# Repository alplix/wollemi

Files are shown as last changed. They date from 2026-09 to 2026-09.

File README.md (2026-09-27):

# Wollemi

> **Private for now.** The repository will be opened to the public once the design is complete. No licence has been applied yet; the plan (`docs/licensing.md`) is CERN-OHL-S-2.0 for hardware,
> Apache-2.0 for software and CC-BY-4.0 for documents. Analysis-level design only: no hardware exists, nothing here is qualified for flight, and every number is an engineering estimate.

Wollemi is an open, modular, fully documented small-satellite **platform** and a first mission built on it: a science-first, long-life **12U observatory** with a tiered 50-year survival design.
Everything is generated from configuration files and checked by tools, so a derived mission is a configuration change plus new cards.

*Türkçe özet:* Wollemi, açık kaynak, modüler bir küçük uydu platformu ve üzerine kurulu ilk görev: uzun ömürlü, bilim öncelikli 12U gözlemevi. Tasarım analiz düzeyinde tamamlandı (donanım yok);
her sayı config dosyalarından üretilen araçlarla doğrulanıyor. Depo şimdilik özel, tasarım olgunlaşınca herkese açılacak.

## Where things stand

The design is **complete at analysis level**: requirements, architecture, CAD with interference checks, power/thermal/attitude/orbit/structure analyses, protocol and firmware core with tests,
electronics interface (KiCad, DRC clean), FMEA, test plan, operations concept, cost and schedule. Start with **`docs/sdd.md`** (system design document) and **`docs/status.md`** (latest regression).
What is missing is physical: vendor data, schematics of the functional cards, prototypes, tests, a launch and an operator. See `docs/plan.md`, `docs/risks.md` and `docs/cost.md`.

| At a glance | Value |
|---|---|
| Form | 12U CubeSat envelope, 2 x 2 x 3 cell grid around a central spine, notched 100 x 100 mm cards |
| Mass / power | about 16.8 kg of 24 kg; 58 W sun-biased, 28 W tumbling, 3 W safe-mode load |
| Science | ~26 instruments: telescope (5 m class) + hyperspectral, thermal IR, magnetometer, particles, X-ray/UV, TSI, VLF, GRB, dosimetry, SEU/flash experiments |
| Compute | MSP430 supervisor, 2 x STM32H7, mass memory unit (8 x 128 GB, 6+2), Pi CM5, Jetson Orin Nano |
| Power | two LiFePO4 chains + independent survival chain, hardware-only protection |
| Propulsion | iodine electric thruster on the centre line, ~570 m/s available (about 190 m/s planned), drag sail |
| Verification | 47 requirements traced (see `docs/verification-matrix.md`); most checked automatically on every run; 29 planned tests |

## Documentation

| Topic | Read |
|---|---|
| Overview | `docs/sdd.md`, `docs/plan.md`, `docs/status.md` |
| Requirements and verification | `mission/requirements.md`, `docs/verification-matrix.md`, `docs/test-plan.md`, `docs/fmea.md`, `docs/risks.md` |
| Design | `docs/architecture.md`, `docs/layout.md`, `docs/structure.md`, `docs/icd.md`, `mechanical/README.md` |
| Power, thermal, attitude, propulsion | `docs/power-architecture.md`, `docs/eps-card.md`, `docs/thermal.md`, `docs/adcs.md`, `docs/propulsion.md`, `docs/orbit-and-debris.md` |
| Electronics, software, data | `docs/electrical-interface.md`, `docs/firmware-architecture.md`, `docs/protocol.md`, `docs/data-plan.md`, `docs/mission-simulation.md` |
| Operations and ground | `docs/ops-concept.md`, `docs/ground-station-kit.md`, `docs/longevity.md` |
| Context | `docs/sponsor-brief.md`, `docs/relay-policy.md`, `docs/prior-art.md`, `docs/design-identity.md`, `docs/decisions/`, `docs/outreach-led.md`, `docs/cost.md`, `docs/licensing.md`, `CREDITS.md` |

## Repository layout

| Path | Content |
|---|---|
| `configs/` | Single source of truth: science, geometry, layout, data, longevity, thermal, structure, cost (+ 2U/3U/6U variants) |
| `mission/` | Requirements, `traceability.toml` (requirement -> verification), `tests.toml` (planned tests), `fmea.toml` |
| `sim/` | Budgets, layout rules, balance, data, longevity, link, EPS, ADCS, thermal, structure, orbit lifetime, mission simulation, cost, LED visibility, live verification matrix |
| `mechanical/` | Voxel packing, parametric build123d assembly, interference/mass properties, STEP/STL/renders |
| `electronics/` | Connector pinout (single source), KiCad card template and 15-slot backplane strip (DRC clean), EPS diagram, EPS/survival card floor plans (DRC clean, not yet a schematic) |
| `protocol/` | Message definitions, C/Python/Kaitai Struct generators, tests (round trip, corruption, byte-exact C <-> Python, Kaitai model verified against a real compiler) |
| `firmware/` | Host-testable core: Ed25519 command authentication, modes, FDIR, command queue, A/B OTA (84 unit checks + signature cross-checks) |
| `groundstation/` | Pass prediction, contact plan, reference decoder, Kaitai Struct decoders for the whole protocol |
| `tools/` | `check_all.py` (whole regression), FMEA, test-plan and requirement checks, generators for the ICD and the SDD |
| `site/` | Draft project website (English), prepared but not published -- repository is still private (`site/README.md`) |

## Quick start

```
pip install build123d cryptography sgp4       # CAD kernel, signing tests, orbit propagation (numpy, scipy, pillow come with build123d); KiCad 10 optional for DRC
python tools/check_all.py                     # runs every analysis and test, writes docs/status.md   (--quick skips CAD, thermal and the verification matrix)
python sim/trace_check.py                     # live requirements verification matrix
python mechanical/wollemi_cad.py               # full CAD assembly and checks, exports into mechanical/out/
python tools/gen_sdd.py                       # regenerate the system design document
```

Requires Python 3.11+ and GCC for the firmware and protocol tests. The `sim/` tools use only the standard library unless noted.

## Status and next steps

Design freeze candidate v0 at analysis level. The decisions that shape everything next: choose the target (flight mission, flight-quality reference design, or the precursor path with a FlatSat and a balloon flight),
confirm the preferred orbit, and get vendor quotes and datasheets. Details in `docs/sdd.md` section 8.

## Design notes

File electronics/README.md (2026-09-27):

# Electronics

| File | Role |
|---|---|
| `card_pinout.toml` | Single source for the WL-P and WL-D connector pinouts and the card outline |
| `gen_card.py` | Generates the KiCad card template and `pinout.md`, runs `kicad-cli` DRC (needs KiCad 10) |
| `kicad/wollemi_card_template.kicad_pcb` | 100 x 100 mm card with the 20 x 20 mm spine notch, 4 x M2.5 holes, edge-guide keep-outs, WL-P and WL-D connector placeholders with every net assigned |
| `kicad/wollemi_card_template.svg`, `_top.png` | Renders |
| `gen_backplane.py` | Generates the 15-slot passive backplane strip (one per column), runs `kicad-cli` DRC |
| `kicad/wollemi_backplane_strip.kicad_pcb` | Passive backplane strip: 15 card slots, WL-P/WL-D routing per chain, DRC clean |
| `gen_eps_card.py` | Generates function-block floor plans for the EPS-A/EPS-B and survival cards on the real card outline (`docs/eps-card.md`), runs `kicad-cli` DRC |
| `kicad/wollemi_eps_card.kicad_pcb`, `wollemi_survival_card.kicad_pcb` | Floor plans only: labelled placeholder blocks proving the partition fits the card, DRC clean; not a routed schematic |
| `eps_diagram.py` | Generates the EPS block diagram `eps_diagram.svg` |
| `pinout.md` | Generated pin tables |

```
python electronics/gen_card.py
python electronics/gen_backplane.py
python electronics/gen_eps_card.py
```

The card template has no routing yet: `unconnected_items` and generated-library warnings are silenced in its project file on purpose. Cards derived
from it must re-enable them. Connector footprints are placeholders (2-row, 1.27 mm pitch pads); replace with the vendor footprint once the
connector family is chosen (`docs/electrical-interface.md`).

Next: choose real parts and capture a routed schematic for the EPS and survival cards (`docs/eps-card.md`); a first functional (non-EPS) card schematic.

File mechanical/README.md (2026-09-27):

# Mechanical model (parametric CAD)

Everything is generated from the TOML configs; nothing is hand-drawn.

| File | Role |
|---|---|
| `../configs/12u_geometry.toml` | Frame, wings and a bounding box (mm) for every module; flags `fixed`, `shape = "cyl"`, `notched`, `end = "nadir"/"zenith"`, `align = "top"` |
| `pack.py` | Voxel packing (2.5 mm) of every box into its assigned column/deck; maximum-contact placement, disk footprints for cylinders, corner-notched card format; writes `out/placement.json` |
| `wollemi_cad.py` | build123d / OpenCascade assembly: rails, walls, plates with windows, bulkheads, spine, modules, wings, antennas, thruster nozzle; exact boolean interference check; centre of mass and inertia; STEP, STL, renders, BOM |

```
pip install build123d            # OpenCascade based CAD kernel (also pulls numpy, scipy, pillow)
python mechanical/pack.py        # packing report
python mechanical/wollemi_cad.py  # full assembly, checks, exports into mechanical/out/
```

Outputs in `out/`: `wollemi_12u_stowed.step/.stl`, `wollemi_12u_deployed.step/.stl`, `render_*.png`
(stowed, deployed, interior, cutaway, nadir), `bom_geometry.csv`, `placement.json`.

## What the geometry taught us

- **Volume was not the problem, footprint was.** The 20 x 20 mm spine notch at every column's inner corner
  stops any 90 x 90 mm or 100 x 100 mm board. Fix: the **Wollemi card format**, a board with its own
  20 x 20 mm corner cut-out that seats against the spine.
- A 100 mm-wide telescope tube only fits as a **round** Ø95 mm tube; a square 100 mm box does not fit.
  The 90 mm aperture therefore became ~85 mm (about 5 m ground sampling at 700 km).
- Modules with windows (wide-field camera, thermal IR, lightning) must sit against the nadir plate;
  the star tracker, GNSS, boom and antenna deployer against the zenith plate (`end` flag).
- The propulsion column (Q2) is vertically almost full: cameras + ADCS + tank + star tracker = ~333 of
  334.5 mm. Any growth there needs a design decision.
- Stowed wing stack: 3 x 2.1 mm = 6.3 mm, inside the 6.5 mm protrusion allowance (2.2 mm panels would fail).
- Thruster: the propulsion bay sits on the -X face centre line with the nozzle canted through the centre of mass; the plume (12 degrees half-angle, gridded ion)
  is checked against the wings by `mechanical/wollemi_cad.py` (a wider Hall-type plume would impinge on panels 2-3).

- **Thruster line vs centre of mass:** with the nozzle in a column the lever arm was ~70 mm (about 70 uN m at 1.1 mN). The propulsion module is now a bay on the -X face centre
  line (keep-out in Q2/Q3) with a fixed cant of about 3.9/5.8 deg through the CoM (after a 1.7 kg tungsten trim ballast in Q2); that cant also clears the exhaust from wing B. See `docs/adcs.md`.
- **Wings must be double-sided:** with the sun on +Y in a dawn-dusk orbit, one single-sided wing faces away; the power scenarios assume cells on both faces.

## Limits (be honest)

- Modules are bounding boxes (cylinder for telescope and tank), not vendor CAD; sizes are estimates.
- No fasteners, harness, brackets, thermal straps or shielding walls are modelled yet.
- Body solar cells are not modelled as a skin layer (their thickness counts against the protrusion limit
  on faces without wings).
- The dispenser interface (rails, tabs, springs) is simplified: check against the chosen dispenser drawing.

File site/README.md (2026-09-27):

# Wollemi project website (draft, English)

A single self-contained static page (`index.html` + `assets/img/`) introducing the mission, gallery renders and
deployment animation, in English, for eventual public release.

**Status: prepared, not published.** The repository is still private (`README.md`, `docs/licensing.md`); this
page is not deployed anywhere and GitHub Pages is not enabled. It sits in the repository so it is ready to
publish once the operator decides to open the design to the public.

## Regenerating the images

All images in `assets/img/` are copies of `mechanical/out/gallery/*`, from three generators, all built on
`mechanical/wollemi_cad.py` (the real parametric CAD model):

- `mechanical/render_gallery.py`: technical views, exploded view, three-view drawing, GIFs -- flat per-part
  colours, for engineering clarity.
- `mechanical/render_space.py`: quick "in orbit" illustrations using this project's own lightweight rasteriser,
  with a solar-cell grid and gold MLI foil texture painted on afterwards -- fast, no extra tools needed, but
  the shading is not physically simulated.
- `mechanical/render_blender.py` (needs a separate Blender install, see below): the same CAD geometry rendered
  by a real path tracer (Cycles) with proper PBR materials, a real NASA Earth photograph and simulated
  lighting -- the photorealistic `blender_*.jpg` images. This is the one to use when the goal is "look like a
  real satellite photo", not a technical or schematic illustration.

After changing the CAD model or the geometry configs, regenerate and re-copy:

```
python mechanical/pack.py
python mechanical/render_gallery.py
python mechanical/render_space.py
cp mechanical/out/gallery/*.png mechanical/out/gallery/*.gif site/assets/img/
```

To regenerate the photorealistic renders, a Blender install is needed (tested with Blender 5.2 LTS; a GPU with
Cycles/OptiX support renders in seconds, CPU-only still works but is slower):

```
python mechanical/export_obj.py deployed
python mechanical/export_obj.py stowed
"<path to blender.exe>" --background --factory-startup --python mechanical/render_blender.py -- deployed
"<path to blender.exe>" --background --factory-startup --python mechanical/render_blender.py -- stowed
python -c "from PIL import Image; [Image.open(f'mechanical/out/gallery/blender_{n}.png').convert('RGB').save(f'site/assets/img/blender_{n}.jpg', quality=90, optimize=True) for n in ('deployed','stowed')]"
```

Pass `-- deployed --fast` for a quick low-sample preview (a few seconds) while tuning the camera/Earth/sun
placement in `render_blender.py`, then drop `--fast` for the final 256-sample render.

## Viewing locally

Open `index.html` directly in a browser, or serve the folder so relative paths resolve the same way they would
on a real host:

```
python -m http.server 8000 --directory site
```

## Publishing later

When the operator decides to make the repository public: enable GitHub Pages for this `site/` directory (or copy
it to a `gh-pages` branch), review `docs/licensing.md` first, and see `docs/decisions/` for anything else that
should be resolved before the public link goes out.

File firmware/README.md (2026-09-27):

# Firmware core (host-testable)

Pure C99 logic that will run unchanged on the flight controller and supervisor; hardware access sits behind a HAL that is not written yet.

| Module | Role |
|---|---|
| `common/wl_auth.*` | Telecommand authentication: CRC, TC check, validity window, replay counter, Ed25519 (TweetNaCl), current + previous key |
| `common/wl_modes.*` | Mode manager and degradation ladder (LAUNCH, DEPLOY, COMMISSION, NOMINAL, SCIENCE, SCIENCE_LITE, BURN, ECLIPSE, SAFE, SURVIVAL; levels L0-L3) |
| `common/wl_fdir.*` | Heartbeat monitoring and escalation retry -> restart -> power-cycle -> switch redundant -> degrade |
| `common/wl_cmdq.*` | Time-tagged command queue (absolute time and orbit position triggers, mode masks, validity windows) |
| `common/wl_ota.*` | A/B update state machine with confirm-or-rollback |
| `../protocol/generated/wollemi_proto.h` | Generated packet code shared with the ground software |

```
pip install cryptography
python firmware/tests/run_tests.py     # builds with gcc -Wall -Wextra -Werror, runs 68 unit checks and the Ed25519 cross-checks
```

The cross-checks sign telecommands in Python (`cryptography`) and verify them in C: valid, replay, expired, wrong key, previous key, forged,
tampered with valid CRC, bad CRC, truncated.

Not done yet: HAL, Zephyr integration and drivers, persistent storage of the counter and keys (FRAM), real-time budget, the key-rotation command handler,
the object store client, and a hardware-in-the-loop harness.

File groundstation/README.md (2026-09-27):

# Ground station kit software

| File | Role |
|---|---|
| `predict.py` | Pass prediction, Doppler and pass statistics with SGP4 (`pip install sgp4`) |
| `decode.py` | Reference decoder for Wollemi packets (hex, `.wpk` streams), uses `protocol/generated/wollemi_proto.py` |

```
python groundstation/predict.py --days 7                       # demo orbit, four sites
python groundstation/predict.py --tle L1 L2 --lat 39.93 --lon 32.86 --alt 0.9
python groundstation/decode.py --demo
python groundstation/decode.py --file capture.wpk
```

Design, link margins and hardware plan: `docs/ground-station-kit.md`. Signature verification of telecommands (Ed25519) is still to be added
with a vetted library. The demo orbit is synthetic; use operator-provided elements after launch.

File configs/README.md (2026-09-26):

# Configuration files

| File | Role | Status |
|---|---|---|
| `12u_science.toml` | modules (mass, power, duty, volume, tier), solar geometry, battery, power scenarios | maintained, single source of truth |
| `12u_geometry.toml` | frame, wings and a bounding box per module (flags: fixed, cyl, notched, end, align, tilt) | maintained |
| `12u_layout.toml` | which column and deck each module goes to, plus separation rules | maintained; reconciled with the real packing by `mechanical/reconcile.py` |
| `12u_data.toml` | data streams, link and storage assumptions | maintained |
| `12u_longevity.toml` | degradation, battery cycles and radiation assumptions | maintained |
| `12u_thermal.toml` | coatings, conductances, heaters, limits | maintained |
| `12u_structure.toml` | materials, launch loads, fasteners, wing hold-down | maintained |
| `12u_cost.toml` | rough cost and schedule ranges (unverified) | maintained |
| `2u_baseline.toml`, `3u_science.toml`, `6u_science.toml` | earlier variants (single-estimate budgets, no geometry) | **legacy**: kept for comparison and for the tier idea; not updated with the 12U changes |

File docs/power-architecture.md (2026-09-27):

# Power architecture: fault containment and redundancy (draft v0)

Principle: **no single failure in power may kill the spacecraft.** Every failure is contained
to its own zone by hardware, without relying on software.

## Zones (physically separated)

```
 [Solar strings A,B,C,D]  independent, one per panel group
        |  (blocking diode + fuse per string)
 [MPPT/charger 1] [MPPT/charger 2]        <- two independent EPS boards
        |                 |
 [Battery pack 1]   [Battery pack 2]      <- separate compartments, thermal barrier,
   (own BMS, fuse,     (own BMS, fuse,       vent path away from electronics
    disconnect)         disconnect)
        |                 |
        +---- ideal-diode OR-ing ---- Main bus A / Main bus B
                                        |
                          [per-load latching current limiter (LCL)]
                                        |
                          loads: OBC, Pi, Jetson, ADCS, radio, payloads
```

## Rules

1. **Batteries are isolated**: own enclosure/compartment, thermal barrier (polyimide/ceramic
   fibre), mechanical restraint, vent path directed away from electronics. Each pack has its own
   fuse, cell-level protection and hardware disconnect switch.
2. **Redundant EPS**: two independent EPS boards; either can carry essential loads alone.
3. **Two buses (A/B)** joined by ideal-diode OR-ing; a short on one side cannot pull the other down.
4. **Per-load protection**: every load has a latching current limiter with over-current trip and
   autonomous retry, implemented in hardware and monitored by the MSP430 supervisor.
5. **Independent solar strings** with blocking diodes and fuses; a shorted string is dropped.
6. **Cross-strapping**: essential loads (supervisor, beacon radio, OBC) can be powered from A or B.
7. **Connectors and harness**: separate power and data routing, redundant pins on every power
   connector, no power through a single pin, strain relief, keep-out from battery zone.
8. **No software in the protection path**: OCP/OVP/UVP/thermal cutoffs are analog/hardware.
9. **Cell chemistry**: prefer LTO (no lithium plating, high cycle life, wide temperature) or LiFePO4;
   plain Li-ion only where energy density is needed and containment is proven.
10. **Deployment inhibits**: three independent inhibits before any deployable or propulsion
    energises (launch-provider requirement style).
11. **Degradation ladder**: full mode -> sun-only mode (no battery) -> supervisor + beacon only.

## Trade-offs

More mass, volume and board area (~0.3-0.6 kg, ~0.3-0.5U for 6U). Accepted: reliability and
50-year durability outweigh density for the power subsystem.

## Survival bus (independent emergency source)

A third, fully independent power path: **pack C (2S1P LiFePO4, 5 Wh, 6.4 V nominal, ~780 mAh)** with its own solar string,
charger, BMS, fuse and containment. The 2S configuration matches packs A/B's bus convention on purpose (`docs/eps-card.md`): it lets the survival card reuse the same
charger, ideal-diode and eFuse parts as EPS-A/B (fewer unique parts to qualify and stock for the whole spacecraft), at the cost of needing a small-format LiFePO4 cell
in this capacity class (not yet sourced). It is not connected to buses A/B and feeds only:

- MSP430 supervisor and beacon transmitter
- antenna and wing deployment drivers (burn wire), so deployment never depends on packs A/B
- minimal heater for the survival electronics

Behaviour:
1. After dispenser separation, a timer (with independent inhibits) uses pack C to deploy antenna and wings.
2. In any fault where A/B are lost or shut down, the spacecraft keeps beaconing and can be commanded to recover.
3. Pack C is charged only from its own dedicated body-mounted string so a fault on the main strings cannot drain it.
4. Option under study: a non-rechargeable primary cell as a last-resort backup for deployment only.

Degradation ladder becomes: full mode -> sun-only mode -> supervisor + beacon on survival bus.

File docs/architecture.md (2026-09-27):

# Architecture (v1, 12U observatory)

Overview of how the pieces fit; details are in the documents listed at the end. All numbers are engineering estimates (`docs/sdd.md` has the live values).

## Principle: platform, cells and cards

```
 +--------------------------------- 12U frame (rails, walls, plates) ---------------------------------+
 |  Column Q1        Column Q2          Column Q3            Column Q4              central spine     |
 |  telescope        attitude, optics   compute, comms,      energy vault,          (backplane hub,   |
 |  + spectrometer   + trim ballast     quiet science        hard-radiation science  harness)         |
 |        each column: 3 decks of Wollemi cards (100 x 100 mm, spine notch) on a passive backplane strip |
 |                       propulsion bay across Q2/Q3 on the -X centre line                             |
 +------------------------------------------------------------------------------------------------------+
   wings (2 x 3 double-sided panels), body cells, antennas, apertures on the outer skin
```

- The frame is split into a 2 x 2 x 3 **cell grid** around a 40 mm spine. Every card is 100 x 100 mm with a 20 mm corner notch (clears the spine), an 8 mm outer relief (clears the rail) and a 4 mm gap to the backplane.
  Non-card items (telescope tube, tank, packs, ballast) occupy defined cell volumes. This is close to OreSat's card/backplane idea; the grid, notched card and machine-checked rules are ours (`docs/prior-art.md`).
- A new mission changes the configuration files and the cards; the bus, the tools and the protocol stay.

## Subsystems in one page

| Subsystem | Architecture | Key document |
|---|---|---|
| Structure | Al frame, corner rails, four columns, hold-down posts for wing stacks | `docs/structure.md` |
| Power | two independent MPPT/battery chains (A, B) plus an independent survival chain (C); per-card eFuse, hardware kill, no software in the protection path | `docs/power-architecture.md`, `docs/eps-card.md` |
| Thermal | passive with MLI patches (effective emissivity ~0.5), isolated telescope column, battery vault and survival heaters | `docs/thermal.md` |
| Attitude and propulsion | wheels, torquers, star tracker; iodine thruster on the centre line, canted through the CoM; drag sail | `docs/adcs.md`, `docs/propulsion.md` |
| Compute | supervisor (MSP430FR), two flight controllers (STM32H7), mass memory unit, Pi CM5, Jetson | `docs/firmware-architecture.md` |
| Data and comms | CCSDS packets with signed commands, CAN-FD A/B control plane, Ethernet data plane, UHF and S-band | `docs/protocol.md`, `docs/data-plan.md` |
| Payload | 26 instruments; long-life science chain acquired by the flight controllers, imaging by the Linux computers | `docs/data-plan.md`, `docs/layout.md` |
| Ground and operations | open S-band kit, unattended reference station, contact plan | `docs/ops-concept.md`, `docs/ground-station-kit.md` |

## Reliability approach (COTS in LEO)

- **Tiers** (`docs/longevity.md`): survival chain (50+ years), long-life science chain (30-50), heavy compute (10-15), main batteries (10-28).
- Three independent power paths; every card protects itself in hardware; the supervisor can kill any slot without firmware (`SLOT_SEL`, `KILL_N`).
- Latch-up protection per card, ECC and scrubbing, critical data in FRAM with checksums, erasure-coded mass memory, a graded-Z (Ta/Al) radiation vault for the control electronics.
- Degradation ladder L0-L3 with modes NOMINAL, SCIENCE, SCIENCE_LITE, ECLIPSE, BURN, SAFE, SURVIVAL (`docs/mission-simulation.md`).
- Failure modes covered in `docs/fmea.md`; verification in `docs/verification-matrix.md` and `docs/test-plan.md`.

## Density levers used

1. Deployable double-sided wings on top of body cells (largest power gain).
2. Shared optics (hyperspectral behind the telescope), cards packed by contact-maximising 3D packing.
3. Dense shielding metal (tantalum) where volume, not mass, is the constraint.
4. Duty cycling with battery buffering and a burn mode that cuts every other load.
5. On-board processing and priority queues to fit the science data into the S-band pass budget.

## Scaling

Form factor and module lists are configuration (`configs/`): the 2U, 3U and 6U files are earlier variants kept for comparison (`configs/README.md`); the 12U configuration is the maintained design.

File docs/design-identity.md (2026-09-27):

# Design identity (draft v0): what makes this design ours

Project name: **Wollemi**. The wollemi is a "living fossil" that has survived for ~270 million
years, which is the design philosophy: build for decades, degrade gracefully, never die of a
single fault.

## What is new, what is borrowed

See `docs/prior-art.md` for the honest comparison with OreSat, LibreCube, UPSat and others. In short: the
card/backplane idea is **not** ours (OreSat is the closest precedent); our contribution is the combination below.

We do not claim to have invented every part. We claim a distinctive *combination*, published
openly, and we document prior art honestly. A `docs/prior-art.md` review is part of phase 1.

### Distinctive contributions

1. **Wollemi Cell Standard (WCS)** (close to OreSat's card/backplane; the differences are the grid, spine, notched card and checked rules). The 12U body is a 2 x 2 x 3 grid of ~113 mm cells around a
   central spine and cross bulkheads. Each payload is a self-contained "cassette" occupying a
   defined number of cells, with fixed mechanical, thermal, power and data interfaces. New
   missions re-use the bus and swap cassettes. The cell grid is derived directly from the
   deployer envelope (226 x 226 x 340 mm = 2 x 2 x 3 cubes), so it adapts to 3U..24U.
2. **Design rules as code.** Thermal and electromagnetic separation rules (magnetometer far from
   batteries and wheels, telescope opposite the hot computer, packs in separate decks, ...)
   live in `configs/12u_layout.toml` and are checked automatically by `sim/layout_check.py`.
   Every design revision is machine-verified against them.
3. **Three-layer power isolation.** Packs A and B (main), plus an independent survival pack C
   with its own string and charger, hardware-only protection, and a degradation ladder down to
   beacon-only (see `docs/power-architecture.md`).
4. **Dual-computer radiation experiment.** A Raspberry Pi CM5 and a Jetson Orin Nano fly side
   by side, each supervised by an MCU, and their error rates are compared as science data.
5. **Science-first mass and volume allocation.** Payload value ranking drives the layout; the
   spacecraft carries a 26-instrument suite designed for long, continuous data records
   (irradiance, magnetic field, radiation, plasma, ionosphere).
6. **Longevity artefacts.** Laser retroreflector for decades of precise orbit tracking; sapphire
   / nickel memory plate carrying the open design archive; open protocol and open ground software
   so the mission outlives its original operators.
7. **Config-driven everything.** Mass, power, volume, layout and scenarios all derive from TOML
   files, so a derived mission is a config change plus new cassettes.

### Borrowed (and credited)

- CubeSat Design Specification (Cal Poly CDS) for envelope and rails.
- CCSDS / CFDP-style file delivery, AX.25 amateur framing, SatNOGS-style volunteer ground network.
- Common COTS parts and open toolchains (STM32, MSP430, Raspberry Pi, Jetson, Zephyr/FreeRTOS).

### Optional visual signature (to decide in the mechanical phase)

- Wollemi-leaf fan deployment for the solar wings (single pivot, single release line, fewer
  mechanisms). Trade-off: less efficient use of rectangular cell area. To be evaluated.
- Distinctive solar cell pattern and marking on the panels; engraved emblem on the memory plate.

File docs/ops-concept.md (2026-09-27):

# Operations concept and commissioning plan (draft v0)

Companion documents: `docs/mission-simulation.md` (mode behaviour), `docs/firmware-architecture.md`, `docs/fmea.md` (anomaly responses), `docs/data-plan.md`, `mission/requirements.md`.
Tool: `python groundstation/contact_plan.py` (passes and roles for the reference station).

## 1. Phases

| Phase | Duration | Goal | Mode |
|---|---|---|---|
| Pre-launch | months | integration, functional and environmental tests, remove-before-flight, launch approval | powered off (RBF) |
| Separation and deployment | first 1-2 h | timer (no RF, no deployment until >= 30 min), antenna and wing deployment from the survival supply | LAUNCH, DEPLOY |
| LEOP | days 0-3 | first contact, beacon decode by any listener, detumble, sun acquisition, time set | COMMISSION / SAFE |
| Commissioning | days 3-30 | checkout of every subsystem, calibration, first burn, first images | COMMISSION -> NOMINAL |
| Routine science | years | long-life record plus imaging campaigns; station keeping and collision avoidance | NOMINAL, SCIENCE, SCIENCE_LITE, ECLIPSE, BURN |
| Extended life | decades | degraded operation along the tiers (`docs/longevity.md`) | SAFE / sun-only / survival |
| End of life | months | disposal manoeuvre, passivation | BURN then survival beacon |

## 2. Ground segment and contact plan

- Reference station: Pamukkale (37.9 N, 29.1 E): about 3.7 passes/day of ~7.5 min. In the dawn-dusk orbit the passes fall in **two clusters per day**: around 05-08 h local (dawn side) and around 18-20 h local (dusk side)
  (a dawn-dusk orbit crosses every latitude at about 06:00 and 18:00 local time). **The station must run unattended**: scheduled tracking, automatic decode and upload of the received data to the open archive, alarms on missed passes.
- Pass roles each day: first pass = command upload and time synchronisation; highest-elevation pass = bulk S-band downlink; low passes = UHF housekeeping. About 23 min/day of usable S-band contact
  (`groundstation/contact_plan.py`), enough for the ~44 MB/day of science data plus imaging (`docs/data-plan.md`).
- Redundancy: a second station (or the volunteer network) is needed for commanding continuity; a single outage removes a day of contacts (FMEA COM-04).
- Commanding: all commands are time-tagged sequences loaded 24-48 h ahead (COLAV-2), validated on the ground against the power, attitude and thermal state (`wl_cmdq`, `wl_auth`), signed with the operational key.

## 3. Launch and early operations (LEOP)

1. Separation detected; timer of 30 minutes (no RF, no deployments); the survival supply deploys the UHF antenna, then the wings; the supervisor confirms with the deployment switches.
2. First beacon (`beacon` packet, decodable by anyone) at the first pass; contact confirmed by the operator or by volunteer stations.
3. Detumble with magnetorquers, sun acquisition; verify generation against the model (>= 28 W tumbling, ~58 W sun-biased); battery state.
4. Time set (`time_set`), key check (a signed no-op telecommand), housekeeping stream review (`hk_power`, `hk_thermal`, `hk_adcs`).
5. Go/no-go for commissioning: power positive, thermal inside limits, attitude controlled, both CAN buses healthy.

## 4. Commissioning checklist (pass criteria link to requirements)

| Step | Check | Pass criterion | Requirement |
|---|---|---|---|
| 1 | Power: pack A/B/C voltages, charge and discharge, string currents | generation within 20 % of the model; all packs balanced | PWR-1, PWR-2 |
| 2 | Thermal: all columns and battery inside limits over two orbits | electronics -20..60 C, battery 0..40 C; heaters cycle as predicted | THM-1, THM-2 |
| 3 | Comms: UHF and S-band links, Doppler tracking, rate adaptation | link margin >= 3 dB at 1 Mbps with a 1.2 m dish | COM-2 |
| 4 | ADCS: wheels, torquers, star tracker, slew and nadir tracking | pointing error within budget, slew 90 deg in 120 s | ADCS-1 |
| 5 | Compute: FC-A/FC-B failover, Jetson and CM5 boot, MMU scrub | heartbeat monitoring, redundancy switching and storage self-test OK | FMEA CMP rows |
| 6 | Time and navigation: GNSS lock, CSAC discipline | time quality bits at maximum | CMP-06 |
| 7 | Payload checkout: magnetometer boom, TSI, dosimeter, particle, X-ray, VLF, GRB, SEU experiments | each instrument health and baseline data valid | FMEA PAY rows |
| 8 | Imaging: dark frames, star fields, first Earth images (telescope, wide-field, thermal IR, hyperspectral) | focus and calibration within spec; data reaches the ground | THM-2, PAY-01 |
| 9 | Propulsion: heater check, low-power test burn, thrust and centre-of-mass torque | measured thrust and wheel momentum consistent with the canted-nozzle model | ADCS-2, PROP-1, PROP-2 |
| 10 | Open access: LoRa relay and public data path | a volunteer station receives and decodes | OPEN-1 to OPEN-7 |

## 5. Routine operations

- **Daily**: ingest the archive, review health, plan the next 48 h of sequences; imaging campaigns (three per day when heavy or light compute is available); science data priority as in `docs/data-plan.md`.
- **Weekly**: check the FDIR event log, scrubbing statistics (`mmu_status`), battery and panel trends, temperatures vs the model; update the atmosphere and orbit forecast.
- **Station keeping**: about 0.8 m/s per year at 700 km on average (`docs/orbit-and-debris.md`), roughly 4 h of thrusting per 1 m/s at 1.1 mN; burn mode only in sunlight with a sun-biased attitude.
- **Collision avoidance**: receive a conjunction data message, assess probability, plan a burn (0.1-0.5 m/s, 1-2.5 h), validate, upload 24-48 h ahead, verify afterwards with GNSS (COLAV-1 to COLAV-4).
- **Updates**: OTA sequence PAY-H, PAY-L, MMU, FC-B, then FC-A (`docs/firmware-architecture.md`); every update is signed, staged, verified and confirmed or rolled back.
- **Data policy**: all data published in the open archive with metadata; nothing encrypted; public relay quotas.

## 6. Anomaly response (summary; details in `docs/fmea.md`)

| Symptom | First response | Follow-up |
|---|---|---|
| No contact at a planned pass | check the station, retry the next pass; second station | after 24 h assume UHF/antenna or attitude problem, use the volunteer network |
| Safe mode entered | read the event log (`event`), confirm the power or thermal cause | recover through NOMINAL after fixing the cause; hysteresis prevents chatter |
| Survival mode | only the beacon is heard | diagnose from beacon data; recovery goes SURVIVAL -> SAFE -> NOMINAL |
| Heavy compute lost | SCIENCE_LITE keeps imaging on the CM5 | reboot or leave off; long-life science unaffected |
| Battery degradation | switch to sun-only operation for heavy loads | eclipse operations reduced; a dawn-dusk orbit avoids the problem |
| Thruster fault | abort burn; log; retry once at low power | plan without manoeuvres; the drag sail is the passive fallback |
| Suspected command compromise | rotate the key with a signed `key_rotate` (root key) | audit log, keep the previous key valid for a fixed period |

## 7. End of life

- Plan the disposal manoeuvre while at least 200 m/s of delta-v remains: propulsive descent to 500-600 km (54-108 m/s, 8-17 days of thrusting), then drag with the sail (`docs/orbit-and-debris.md`).
- Passivation: deplete or vent the propellant heaters and discharge the main batteries. The survival chain that could outlive the mission conflicts with the disposal guideline and must be handled deliberately
  (either accept a documented exception or end it during passivation).
- Hand over the archive, tools and keys according to the governance plan; publish the final data set.

## 8. Staffing and tools (a one-person project needs automation)

- Automated pass scheduling and recording, alarms, an automatic archive uploader, and a web status page.
- Dry runs: mission simulation (`sim/mission_sim.py`), digital twin from the same configuration, replay of recorded telemetry.
- A written on-call and hand-over procedure; two-person rule for manoeuvres and key operations (FMEA GND-01).

## 9. Open items

- A real orbit (launch provider) replaces the synthetic one; regenerate the contact plan; check eclipse seasons for the chosen local time of the node.
- Decide the second station and the operator organisation (licensing).
- Detailed procedures (one page per step), operator training, mission control software selection.

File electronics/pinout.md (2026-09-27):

# Card connector pinouts (generated)

Generated from `electronics/card_pinout.toml` by `electronics/gen_card.py`; do not edit by hand.

## WL-P power and control, 2 x 30

| Pin pair | Row A (odd) | Row B (even) |
|---|---|---|
| 1 (pins 1, 2) | VBAT_A | VBAT_B |
| 2 (pins 3, 4) | VBAT_A | VBAT_B |
| 3 (pins 5, 6) | VBAT_A | VBAT_B |
| 4 (pins 7, 8) | VBAT_A | VBAT_B |
| 5 (pins 9, 10) | VBAT_A | VBAT_B |
| 6 (pins 11, 12) | GND | GND |
| 7 (pins 13, 14) | CAN_A_H | CAN_A_L |
| 8 (pins 15, 16) | GND | GND |
| 9 (pins 17, 18) | CAN_B_H | CAN_B_L |
| 10 (pins 19, 20) | GND | GND |
| 11 (pins 21, 22) | PPS_P | PPS_N |
| 12 (pins 23, 24) | GND | GND |
| 13 (pins 25, 26) | SYNC_P | SYNC_N |
| 14 (pins 27, 28) | GND | GND |
| 15 (pins 29, 30) | SLOT_ID0 | SLOT_ID1 |
| 16 (pins 31, 32) | SLOT_ID2 | SLOT_ID3 |
| 17 (pins 33, 34) | SLOT_SEL0 | SLOT_SEL1 |
| 18 (pins 35, 36) | SLOT_SEL2 | SLOT_SEL3 |
| 19 (pins 37, 38) | KILL_N | FAULT_N |
| 20 (pins 39, 40) | GND | GND |
| 21 (pins 41, 42) | I2C_SCL | I2C_SDA |
| 22 (pins 43, 44) | UART_TX | UART_RX |
| 23 (pins 45, 46) | GND | GND |
| 24 (pins 47, 48) | SWD_CLK | SWD_IO |
| 25 (pins 49, 50) | NRST_DBG | VREF |
| 26 (pins 51, 52) | GND | GND |
| 27 (pins 53, 54) | RESET_N | RSV |
| 28 (pins 55, 56) | RSV | RSV |
| 29 (pins 57, 58) | RSV | RSV |
| 30 (pins 59, 60) | RSV | RSV |

Pin counts: CAN_A_H x1, CAN_A_L x1, CAN_B_H x1, CAN_B_L x1, FAULT_N x1, GND x16, I2C_SCL x1, I2C_SDA x1, KILL_N x1, NRST_DBG x1, PPS_N x1, PPS_P x1, RESET_N x1, RSV x7, SLOT_ID0 x1, SLOT_ID1 x1, SLOT_ID2 x1, SLOT_ID3 x1, SLOT_SEL0 x1, SLOT_SEL1 x1, SLOT_SEL2 x1, SLOT_SEL3 x1, SWD_CLK x1, SWD_IO x1, SYNC_N x1, SYNC_P x1, UART_RX x1, UART_TX x1, VBAT x10, VREF x1

## WL-D data, 2 x 15 (data-plane cards only)

| Pin pair | Row A (odd) | Row B (even) |
|---|---|---|
| 1 (pins 1, 2) | ETH0_P | ETH0_N |
| 2 (pins 3, 4) | GND | GND |
| 3 (pins 5, 6) | ETH1_P | ETH1_N |
| 4 (pins 7, 8) | GND | GND |
| 5 (pins 9, 10) | ETH2_P | ETH2_N |
| 6 (pins 11, 12) | GND | GND |
| 7 (pins 13, 14) | ETH3_P | ETH3_N |
| 8 (pins 15, 16) | GND | GND |
| 9 (pins 17, 18) | LANE0_P | LANE0_N |
| 10 (pins 19, 20) | GND | GND |
| 11 (pins 21, 22) | LANE1_P | LANE1_N |
| 12 (pins 23, 24) | GND | GND |
| 13 (pins 25, 26) | GND | GND |
| 14 (pins 27, 28) | RSV | RSV |
| 15 (pins 29, 30) | RSV | RSV |

Pin counts: ETH0_N x1, ETH0_P x1, ETH1_N x1, ETH1_P x1, ETH2_N x1, ETH2_P x1, ETH3_N x1, ETH3_P x1, GND x14, LANE0_N x1, LANE0_P x1, LANE1_N x1, LANE1_P x1, RSV x4

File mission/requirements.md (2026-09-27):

# Wollemi mission requirements (v1, 12U science observatory)

Supersedes the 2U draft. Every requirement with an ID in the tables below is tracked in `mission/traceability.toml` (method, evidence, status) and covered by a planned test in `mission/tests.toml`;
`python tools/req_sync_check.py` keeps this document and the traceability file consistent. Status is in `docs/verification-matrix.md` (generated).

## 1. Mission statement and objectives

**Wollemi** is an open, modular, long-life 12U science observatory and reference platform: it produces multi-decade space-weather, radiation and Earth-observation data, demonstrates robust
electronics and software in orbit, and publishes the design, data and tools for anyone to reuse.

| ID | Objective |
|---|---|
| OBJ-1 | Long-record space-weather and geophysics data: magnetic field, energetic particles, solar X-ray/UV, total solar irradiance, radiation dose, plasma, VLF, gamma-ray bursts. |
| OBJ-2 | Earth observation: 5 m class imaging (telescope), hyperspectral scenes, thermal infrared, wide-field night imagery. |
| OBJ-3 | Technology and reliability science: radiation behaviour of three compute families and of flash memory types over years (open error data). |
| OBJ-4 | A reusable, verifiable open platform: cell grid, notched card, backplane, protocol, firmware core, analysis tools and documentation. |
| OBJ-5 | Open access: public data, public relay, open ground kit and archive; the spacecraft outlives its first operators through the tiered survival design. |

## 2. Figures of merit (`python sim/budget.py configs/12u_science.toml`)

| ID | Metric | Target | Note |
|---|---|---|---|
| FOM-1 | Orbit-average power per U (nominal scenario) | >= 3 W/U | replaced by the density goal "most energy in the least volume" |
| FOM-2 | Eclipse energy margin (usable battery energy / worst eclipse need) | >= 2 | replaces the old Wh/U, which rewarded carrying unused battery |
| FOM-3 | Science payload mass fraction | >= 25 % | mass spent on shielding, redundancy, propulsion and ballast is deliberate for longevity and safety |
| FOM-4 | Science share of module volume | >= 45 % | science-first allocation |

## 3. Requirements

### System and structure

| ID | Requirement |
|---|---|
| SYS-1 | 12U CubeSat envelope (226.3 x 226.3 x 340.5 mm) with rails; deployer-compatible. |
| SYS-2 | Total mass <= 24 kg (deployer limit); planned margin >= 20 % (<= 19 kg). |
| SYS-3 | All modules fit geometrically inside their assigned columns with no interference (exact boolean check). |
| SYS-4 | Centre of mass within 20 mm (x, y) and 70 mm (z) of the geometric centre at launch. |
| SYS-5 | Stowed wing stack thickness <= 6.5 mm protrusion allowance. |
| STR-1 | Fundamental frequencies of the frame, side walls and stowed wing panels >= 100 Hz; all structural margins >= 1 at the design load factor (hand analysis). |

### Power and thermal

| ID | Requirement |
|---|---|
| PWR-1 | Orbit-average power margin >= 20 % in every power scenario (nominal, tumbling, dawn-dusk, safe, burn). |
| PWR-2 | Eclipse energy covered by the usable battery capacity with margin >= 2x. |
| PWR-3 | An independent survival power path (pack C, own string and charger) keeps supervisor and beacon alive when packs A and B are lost. |
| PWR-4 | Solar string voltages stay inside the MPPT input window over the temperature range. |
| PWR-5 | Wing panels carry cells on both faces (needed for the dawn-dusk power scenarios). |
| THM-1 | Electronics stay within -20..+60 C in nominal and eclipse orbits; battery within 0..40 C. |
| THM-2 | Telescope column 10..30 C with swing <= 6 K while imaging. |

### Attitude, propulsion and orbit

| ID | Requirement |
|---|---|
| ADCS-1 | 90 degree slew in 120 s with torque and momentum margin >= 3x. |
| ADCS-2 | Thruster misalignment torque during a burn stays below the magnetorquer average torque (thrust line through the centre of mass +-5 mm). |
| PROP-1 | Total delta-v >= 500 m/s (station keeping to ~700 km, collision avoidance, controlled descent). |
| PROP-2 | Exhaust plume clear of the solar wings. |
| ORB-1 | At end of life the spacecraft can reach reentry within 25 years: passive with the drag sail, plus a propulsive descent option; total delta-v plan within the available budget. |

### Communications, data and software

| ID | Requirement |
|---|---|
| COM-1 | One S-band station at the reference site (Pamukkale) receives all daily science data with >= 2x margin. |
| COM-2 | S-band link margin >= 3 dB at 1 Mbps with a 1.2 m ground dish at 10 degrees elevation. |
| COM-3 | Packet encode/decode is bit-exact between flight (C) and ground (Python) and rejects every single-bit corruption. |
| COM-4 | Telecommands carry a valid Ed25519 signature, counter and validity window; the supervisor rejects others. |
| DATA-1 | On-board storage holds >= 100 days of raw data and tolerates any two device failures. |
| FW-1 | Mode manager, FDIR escalation, time-tagged command queue and A/B OTA with rollback behave as specified. |
| SIM-1 | Closed-loop simulation of the real mode manager over 60 days with injected faults shows no brownout and correct degradation and recovery. |

### Longevity

| ID | Requirement |
|---|---|
| LONG-1 | Survival chain (supervisor + beacon) operates from body cells without any battery (sun-only mode). |
| LONG-2 | Long-record science instruments never depend on Linux nodes for acquisition or downlink. |
| LONG-3 | Main packs still cover eclipse after 10 years in an eclipse orbit (a dawn-dusk orbit has none); safe-mode power holds for 50 years (with the modelled degradation). |

Design life: a **tiered lifetime** (`docs/longevity.md`): survival chain 50+ years, long-life science chain 30-50 years, heavy compute about 10-15 years, main batteries about 10-28 years.

### Electronics and quality

| ID | Requirement |
|---|---|
| ELEC-1 | Card template passes KiCad DRC with the spine notch, connectors and keep-outs defined. |
| ELEC-2 | Column backplane strip (15 slots + hub, bussed CAN/PPS/SYNC/SLOT_SEL/KILL/FAULT/RESET/I2C, GND and battery planes) passes DRC with zones refilled and no unconnected items. |
| ELEC-3 | EPS cards specified (A/B chains and survival chain, hardware-only protection); schematics captured. |
| FMEA-1 | FMEA covers all subsystems; every failure mode of severity >= 4 has a detection and a response. |

### Open access, safety and regulation

| ID | Requirement |
|---|---|
| OPEN-1 | All design files, data and protocol are public under open licences (hardware CERN-OHL-S-2.0, software Apache-2.0, documents CC-BY-4.0). |
| OPEN-2 | Once launched, the spacecraft is open to everyone: anyone with a low-cost station can receive telemetry and payload data. |
| OPEN-3 | Public relay service: any licensed amateur can send and fetch short messages through the store-and-forward payload. |
| OPEN-4 | All downlinked data is unencrypted and the protocol is fully documented (amateur-band rule: no obscured meaning). |
| OPEN-5 | Only spacecraft control commands are authenticated (signed, not encrypted); public relay traffic needs no key. |
| OPEN-6 | Rate limits and message quotas protect the relay from flooding; policy documented. |
| OPEN-7 | Data published continuously in an open archive (for example SatNOGS DB). |
| COLAV-1 | Operator of record registered for conjunction data messages; collision-avoidance burns validated on the ground. |
| COLAV-2 | Avoidance burns are uploaded 24-48 h ahead (propulsion, stable attitude and about 53 W available during the burn). |
| COLAV-3 | Precise orbit knowledge: dual-frequency GNSS plus laser retroreflector; GNSS-derived ephemerides shared with tracking services. |
| COLAV-4 | At least two reliable anchor ground stations guarantee command opportunities at least daily; the volunteer network supplements them. |
| COLAV-5 | Impact detection is for science and status only; small untracked debris is countered by design margin, not avoidance. |
| COLAV-6 | Passivation and end-of-life: propulsive descent or drag sail; propellant reserve kept for disposal. |
| LONG-4 | Disposal versus 50 years: the operational life ends with a disposal manoeuvre (or a documented exception) within the 25-year guideline; the 50-year tier is a platform design life. |
| REG-1 | Frequency coordination and amateur-satellite licensing completed before launch. |

Notes on the open-access items: in-orbit open access still requires a licensed operator of record and frequency coordination; the public can use the service, the transmitter licence sits with the operator.
Onboard range sensors are not a viable collision-avoidance method in LEO (closing speeds of 10-15 km/s); avoidance is done from the ground with tracking data.

## 4. Design values that instruments must meet (targets, verified by design analysis only)

| Instrument | Design value |
|---|---|
| Telescope | ~85 mm aperture, about 5 m ground sample at 700 km, 4096-pixel class detector |
| Hyperspectral | about 50 bands 400-1000 nm, shared telescope optics |
| Magnetometer | 3 axes, 10 Hz, deployable boom |
| Particle spectrometer | 16 electron and 16 proton channels, 10 s integration |
| TSI radiometer, dosimeter, X-ray/UV, GRB counts, CSAC, GNSS/TEC | continuous records through the flight controller path (`docs/data-plan.md`) |

## 5. Communications and coverage

A single station sees a LEO spacecraft for about 2 % of the time (3.7 passes/day of 7.5 min at the reference site). Strategy: an open volunteer ground network, store-and-forward messaging, a UHF beacon for
everyone, S-band for science data, and at least two anchor stations for commanding. Relay via commercial constellations is a possible later phase.

## 6. Out of scope for now

Launch procurement, manufacturing, environmental testing (planned in `docs/test-plan.md`), and any warranty or flight-readiness certification of the design (commercial use is permitted by the open licences).

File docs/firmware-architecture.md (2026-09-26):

# Firmware and flight-software architecture (draft v0)

Design rule number one: **the spacecraft must keep producing and returning long-record science even
after the Linux computers are gone.** Everything below follows from the tiered lifetime in
`docs/longevity.md`.

## 1. Processors and roles

| Node | Hardware | OS / runtime | Role | Expected life |
|---|---|---|---|---|
| **SUP** | MSP430FR (FRAM) | bare metal C, tiny cooperative loop | Supervisor: watchdog for every node, power-cycling, beacon, survival mode, key store, deployment sequencer | 50+ yr |
| **FC-A / FC-B** | STM32H7 x2 (hot standby) | Zephyr RTOS, C (Rust for new modules) | Flight controller: mode manager, FDIR, power and thermal control, ADCS, scheduler, TM/TC, long-life instrument data path | 30-50 yr |
| **MMU** | RP2350 / STM32 class | Zephyr or bare metal | Mass memory unit: erasure-coded object store, scrubbing, quotas | 25-50 yr (adaptive stripes) |
| **PAY-L** | Raspberry Pi CM5 | Linux (read-only root, overlay) | Always-on data handling, S-band/CFDP engine, compression, relay | 10-15 yr |
| **PAY-H** | Jetson Orin Nano | Linux (read-only root, overlay) | Heavy compute: imaging pipeline, hyperspectral processing, target selection, AI | 10-15 yr |

Each node has an immutable boot stage (ROM/OTP or write-protected flash) that is never updated in
flight, plus two application slots (A/B).

## 2. Buses

- **Control plane:** CAN-FD, two redundant buses (A and B). Every node is on both. Carries commands,
  housekeeping, time, mode changes, heartbeat. Low rate, robust, deterministic.
- **Data plane:** switched Gigabit Ethernet between PAY-L, PAY-H, MMU and the S-band modem.
- **Point-to-point:** UART/SPI/I2C from FC to each instrument; PPS discrete lines for time.
- **Power switching:** each node and instrument behind a latching current limiter controlled by FC and SUP.

Time: CSAC + GNSS PPS disciplined time base on FC-A; distributed over CAN-FD; all data stamped in TAI
with the clock quality flag.

## 3. Layers (per node)

1. Boot stage (immutable) + A/B image selection + confirm-or-rollback.
2. RTOS and drivers (Zephyr baseline; the kernel sits behind a thin OS-abstraction API so it can be
   replaced later).
3. Component framework: components with typed ports (commands, telemetry, events, parameters),
   generated from one protocol description shared by flight and ground.
4. Application components (instrument drivers, ADCS, power, thermal, scheduler, mode manager, FDIR).
5. Data services: CCSDS Space Packets, CFDP file transfer, object store client.

## 4. Modes and degradation ladder

`LAUNCH/DEPLOY` -> `COMMISSION` -> `NOMINAL` <-> `SCIENCE` (imaging campaigns) <-> `BURN` (electric
thruster, minimal services) <-> `ECLIPSE` (heavy loads off) -> `SAFE` -> `SURVIVAL`.

| Level | What runs | Trigger |
|---|---|---|
| L0 full | everything | normal |
| L1 no heavy compute | FC, MMU, long-life science chain, comms; Jetson off (Pi optional) | PAY-H or PAY-L lost, or power/thermal limits |
| L2 sun-only | SUP, FC, beacon, long-life science while lit | main packs faded (see longevity) |
| L3 survival | SUP + beacon on the survival bus, direct from the solar string | FC loss, deep power fault |

Transitions are decided by SUP (hardware watchdog, power state) and FC (FDIR); FC cannot override SUP.

## 5. The long-life science chain (mandatory rule)

Instruments with multi-decade records (magnetometer, TSI radiometer, dosimeter, particle spectrometer,
X-ray/UV monitor, GRB counts, CSAC, housekeeping, attitude, SEU/flash experiments):

- are acquired and time-stamped by **FC**, never by Linux nodes;
- are logged as CCSDS packets straight into the **MMU** (and a small FRAM ring as backup);
- are downlinked by the FC/MMU path (CFDP over the S-band modem's serial/Ethernet port, or over UHF for
  priority-1 subsets) even when PAY-L and PAY-H are dead;
- use **self-describing, versioned formats** so the archive stays readable in 50 years.

`sim/chain_check.py` (part of the regression) fails if a long-life stream declares a Linux data path.

## 6. Mass memory unit protocol

- Append-only, log-structured **object store**: object = header + payload; each block carries CRC-32C,
  each object a BLAKE2 hash and a priority class (P1..P3).
- **Erasure coding 6+2** across 8 devices; stripe width narrows automatically as devices die
  (rebuild, then re-stripe); catalogue replicated in FRAM on SUP-independent storage plus the MMU.
- Periodic **scrubbing** (read, verify, rewrite) scheduled around thermal and power state; radiation-induced
  bit errors corrected before they accumulate.
- Quotas per priority: raw ring buffer with automatic eviction; P1 data is never evicted before it is
  acknowledged by the ground (CFDP finished + hash confirmed).
- Interfaces: control over CAN-FD, bulk over Ethernet (put/get/list/verify/delete-after-ack).

## 7. Commanding, security and open access

- **Control commands** are signed (Ed25519) with a monotonically increasing counter and a validity window;
  key hierarchy: offline root key, rotating operational keys, keys stored in SUP FRAM (never in Linux).
  Signed, not encrypted: everything stays readable on the air (amateur-band rule).
- **Public relay traffic** (LoRa store-and-forward, telemetry) needs no key; it is rate limited and quota
  bound on PAY-L, isolated from control (separate VLAN and no path to FC commands).
- **Time-tagged command queue** on FC: absolute time or orbit-position triggers, with dependency and
  abort conditions; survives resets (FRAM-backed).
- Collision-avoidance burns are ordinary time-tagged sequences validated on the ground against power, attitude
  and thermal state (sun-biased, minimal-service burn mode).

## 8. Onboard tasking and autonomy

- Ground uploads **goals** (targets, cadence, priority); PAY-H proposes a plan (cloud cover, sun angle,
  storage, energy) and FC validates and executes it. If PAY-H is dead FC falls back to pre-loaded schedules.
- Imaging pipeline: PAY-H selects and compresses; results go to MMU with metadata; PAY-L handles the downlink
  queue by priority (P1 first, imaging fills the remainder).
- Data budget and priorities follow `configs/12u_data.toml`.

## 9. Updates (OTA)

- Signed manifest + hash; chunked transfer via CFDP over many passes, resumable; delta updates where possible.
- Written to the inactive slot, verified, then booted once; the node must send a **confirm** to SUP/FC within
  a timeout or the boot stage rolls back.
- Order for multi-node updates: PAY-H, PAY-L, MMU, FC-B, then FC-A (the standby is always updated first).
- The boot stage and SUP core are never updated in flight; SUP parameters and non-critical modules may be.

## 10. FDIR

- Heartbeats over both CAN buses, watchdogs (hardware on every node, supervised by SUP).
- Fault tree per subsystem (power, thermal, comms, attitude, storage, compute) with staged responses:
  retry -> restart component -> power-cycle node -> switch to redundant unit -> lower degradation level.
- Latch-up and over-current handled in hardware (LCLs) with SUP retry policy; SEU handling via ECC,
  scrubbing and TMR-style voting on critical variables (FC-A/FC-B compare).
- Every FDIR action is logged as a P1 event.

## 11. Verification and tooling

- One flight code base; hardware-in-the-loop and software-only runs use the same binaries against a digital twin
  driven by the `sim/` models (power, thermal, orbit, data budget).
- Configuration lives in the same TOML files as the design (`configs/`), so a derived mission changes
  configuration, not code.
- Protocol description (packets, files, commands) is a single source that generates both flight and ground code
  (`groundstation/decode.py`, `docs/protocol.md`).

## 12. Open items

- Choose the component framework (F Prime or a small in-house one) and Zephyr vs Rust runtime per node.
- Detailed protocol specification, file formats and archive package format.
- FC-A/FC-B hot-standby scheme (lockstep vs primary/monitor) and clock strategy.
- Key ceremony, revocation and the operator-of-record process (needs the licensed operator, see requirements).
- Real-time budget and CPU/memory sizing per node once instruments are chosen.

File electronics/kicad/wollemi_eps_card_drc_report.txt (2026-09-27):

** Drc report for wollemi_eps_card.kicad_pcb **
** Created on 2026-09-27T15:39:25 **
** Report includes: Errors, Warnings, Exclusions **

** Found 0 DRC violations **

** Found 0 unconnected pads **

** Found 0 Footprint errors **

** Ignored checks **
    - Footprint has no courtyard defined
    - Track endpoint not centered on via
    - Tuning profile track geometries
    - Footprint doesn't match symbol's footprint filters
    - Missing connection between items
    - Footprint component type doesn't match footprint pads
    - Footprint not found in libraries
    - Footprint doesn't match copy in library

** End of Report **

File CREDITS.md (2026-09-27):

# Credits (draft)

Wollemi builds on the work of many open projects and communities. Nothing here implies endorsement by any of them.

## Closest precedents and inspiration

- **OreSat** (Portland State Aerospace Society and collaborators): open-source card/backplane CubeSat architecture, CAN bus with CANopen, open software framework. Wollemi's card and backplane concept is closest to OreSat and follows its CANopen conventions (`docs/decisions/0001-oresat-interoperability.md`).
- **LibreCube**, **UPSat** and the **Libre Space Foundation**, **AcubeSAT**, **EIRSAT-1**, **PULSE-A**: open-source satellite hardware and software, standards use (ECSS, CCSDS).
- **SatNOGS** and **TinyGS**: volunteer ground station networks and open satellite databases.
- **AMSAT** and **AMSAT-OSCAR 7**: proof that a satellite can outlive its battery and its first operators; sun-only survival mode.
- **ThrustMe**: first in-orbit demonstration of an iodine gridded-ion thruster; the propulsion assumptions use its published class figures.
- **CubeSat Design Specification** (Cal Poly and the CubeSat community): the envelope and rails.
- **CCSDS** standards (Space Packet, CFDP) and **AX.25** amateur packet radio.

## Software and tools used

- **KiCad** (electronics, DRC), **build123d** and **OpenCascade** (CAD), **numpy**, **scipy**, **Pillow**, **cryptography** (Ed25519 signing on the ground side), **sgp4** (orbit propagation), **Blender/Cycles** (the photorealistic renders in `mechanical/out/gallery/blender_*`), Python and GCC.
- **TweetNaCl** (Daniel J. Bernstein, Bernard van Gastel, Wesley Janssen, Tanja Lange, Peter Schwabe, Sjaak Smetsers): public-domain Ed25519 implementation used for verification in the firmware core (`firmware/third_party/tweetnacl`).
- **NASA Visible Earth "Blue Marble"** (`mechanical/blender_assets/earth_bluemarble.jpg`, land_ocean_ice_cloud_2048.jpg, https://visibleearth.nasa.gov/images/57735): public-domain Earth imagery (Reto Stockli, Robert Simmon and the MODIS teams) used as the Earth texture in the photorealistic renders; not a copyright claim on Earth, only attribution for the specific image.

## People and organisations

To be completed when the project is opened: authors, contributors, reviewers, sponsors, partner organisations, launch and licensing partners.

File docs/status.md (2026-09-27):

# Status (generated)

Generated by `python tools/check_all.py` on 2026-09-27 14:40 UTC. Do not edit by hand.

**23 of 23 checks pass.**

| Check | Result | Key output |
|---|---|---|
| Budget (mass, power, volume) | PASS | Mass: 16.75 kg (margin +7.25 kg) [OK  ] |
| Layout rules | PASS | Column totals: Q1 99%, Q2 54%, Q3 69%, Q4 94% |
| Centre of mass and heat per column | PASS | BOL CoM offset: x -5.8, y -7.3, z +10.8 mm [OK  ] |
| Data budget | PASS | S-band per pass: 36 MB; per station per day: 134 MB |
| Longevity | PASS | Main packs no longer cover eclipse after ~10.4 yr (then: sun-only mode, or survival bus only) |
| Link budget | PASS | 1.2m 27.0dBi +12.6 dB +9.6 dB +6.6 dB +3.6 dB |
| EPS design | PASS | Pack: 2S2P 26650 LiFePO4 = 42 Wh, 4 cells, 340 g cells only (pack incl. BMS and holder about 440 g; config allows 440 g) |
| ADCS sizing | PASS | Candidate wheels: 3 x (momentum 30 mN m s, torque 3 mN m) |
| Protocol tests | PASS | C cross-check: C pack == Python encode (TM and TC), C unpack of Python packet OK, C rejects corruption |
| Firmware tests | PASS | authentication cross-checks: 11/11 OK |
| Thermal model | PASS | NOMINAL, dawn-dusk (beta 80 deg, eclipse 0 min/orbit, battery heater duty 0 %, optics heater 0 %, total heat 17.5 W) -- |
| Geometric packing | PASS | Whole interior: 64.2 % occupied (after rounding sizes up to 2.5 mm) |
| CAD assembly and checks | PASS | 12 overlapping bounding-box pairs tested with exact booleans; 0 interferences |
| Verification matrix | PASS | 47 requirements: 31 auto PASS, 0 auto FAIL, 9 designed (not yet proven), 7 open |
| Structural analysis | PASS | Verdict: 16 of 16 structural checks meet their margin. |
| Orbit lifetime | PASS | Verdict: at 700 km the sail alone gives 14-20 years (meets 25 years on this model, with a factor 2-3 uncertainty), without the sail 45-50 years (fails |
| Mission simulation | PASS | Verdict: closed-loop simulation with the real mode manager: no brownout, correct degradation and recovery in both orbits. |
| Cost estimate | PASS | Total full flight cash P50 4,523,872 USD (range 4,002,132 - 5,091,947); precursor P50 847,012 USD. |
| FMEA coverage | PASS | FMEA coverage OK: 42 failure modes, 10 subsystems, 19 with severity >= 4 fully covered; wrote docs/fmea.md |
| Requirements sync | PASS | REQ SYNC OK: 47 traceability requirements found in requirements.md; informational IDs only in the document: FOM-1, FOM-2, FOM-3, FOM-4, OBJ-1, OBJ-2,  |
| Long-life chain | PASS | CHAIN CHECK OK: 14 long-life streams acquired by the flight controller and stored via the mass memory unit; 3 streams may use the Linux computers |
| Kaitai protocol model | PASS | All 27 messages in wollemi_protocol.ksy match the real encoder output, field by field. |
| Test plan coverage | PASS | TEST PLAN coverage OK: 29 tests, 47 requirements covered, 3 waived, effort 780 days; wrote docs/test-plan.md |

All figures are analysis results on engineering estimates; see `docs/plan.md` for what remains and `docs/risks.md` for what could go wrong.

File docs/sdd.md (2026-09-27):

# Wollemi system design document (generated)

Generated by `python tools/gen_sdd.py` on 2026-09-27 13:56 UTC; numbers are read from the configs and tools, the decision log is hand-written. Everything is an engineering estimate at the current design level (no hardware exists); see `docs/risks.md` and the open items at the end.

## 1. Purpose and document map

This is the single overview of the design. Details live in the documents below.

| Topic | Document |
|---|---|
| Plan and status | `docs/plan.md`, `docs/status.md` |
| Requirements and verification | `mission/requirements.md`, `docs/verification-matrix.md`, `docs/test-plan.md` |
| Architecture, layout, mechanical | `docs/architecture.md`, `docs/layout.md`, `mechanical/README.md`, `docs/structure.md`, `docs/icd.md` |
| Power, thermal, propulsion, attitude | `docs/power-architecture.md`, `docs/eps-card.md`, `docs/thermal.md`, `docs/propulsion.md`, `docs/adcs.md` |
| Electronics | `docs/electrical-interface.md`, `electronics/README.md` |
| Software and data | `docs/firmware-architecture.md`, `docs/protocol.md`, `docs/data-plan.md`, `firmware/README.md` |
| Orbit, longevity, safety | `docs/orbit-and-debris.md`, `docs/longevity.md`, `docs/fmea.md`, `docs/risks.md` |
| Operations and ground | `docs/ops-concept.md`, `docs/ground-station-kit.md`, `docs/mission-simulation.md` |
| Context | `docs/prior-art.md`, `docs/design-identity.md`, `docs/decisions/`, `docs/outreach-led.md`, `docs/cost.md` |

## 2. Mission

A 12U open, long-life science observatory and reusable platform (objectives OBJ-1 to OBJ-5 in `mission/requirements.md`): multi-decade space-weather and radiation records, 5 m class imaging and hyperspectral scenes, reliability science on COTS compute and flash memory, an open ground kit and archive, and a design others can reuse.

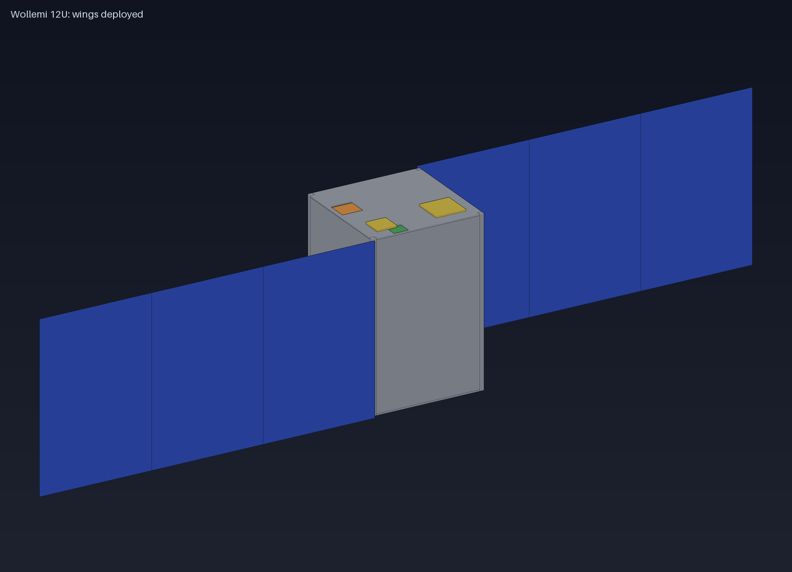
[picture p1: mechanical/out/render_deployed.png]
Stowed and deployed configuration


## 3. Configuration and budgets (live)

| Item | Value |
|---|---|
| Form factor | 12U, 226.3 x 226.3 x 340.5 mm |
| Mass | 16.75 kg of 24 kg (12.3 kg bus, 4.3 kg science, 0.09 kg outreach) |
| Modules | 48 placed in the cell grid, 0 interferences; module volume 10210 cm3 of 10740 cm3 usable (science 52 %) |
| Centre of mass | (-5.8, -7.3, +10.8) mm; inertia (0.198, 0.188, 0.139) kg m2 stowed |
| Average load (full) | 20.4 W; batteries 84 Wh (2 x 42 Wh) plus 5 Wh survival pack |
| Figures of merit | FOM-1 4.85 W/U, FOM-2 x2.7 eclipse margin, FOM-3 26 % science mass, FOM-4 52 % science volume |

Power scenarios (orbit average):

| Scenario | Generation W | Load W | Margin | Eclipse need Wh |
|---|---|---|---|---|
| Typical LEO, ADCS sun-biased (NOMINAL) | 58.2 | 20.4 | +186 % | 12.2 |
| Typical LEO, tumbling, wings deployed | 27.8 | 20.4 | +36 % | 12.2 |
| Dawn-dusk SSO, nadir pointing, wings face sun | 122.2 | 20.4 | +500 % | 0.6 |
| SAFE MODE: tumbling, wings failed to deploy | 10.9 | 3.1 | +251 % | 1.9 |
| BURN MODE: minimal services + electric thruster (sunlit only) | 58.2 | 53.1 | +77 % | 1.9 |

## 4. Subsystem summaries

**Structure.** Al 6061 frame with corner rails, four columns around a 40 mm spine, notched Wollemi cards; first mode about 900 Hz (frame), 170 Hz walls, 190 Hz wing stack with six hold-down posts; all mounts >= 6x margin (`docs/structure.md`).

**Power.** Two wings of three double-sided panels plus body cells; two independent EPS chains (three buck MPPT channels each), two LiFePO4 packs and an independent survival chain; per-card eFuse and hardware kill (`docs/power-architecture.md`, `docs/eps-card.md`).

**Thermal.** Passive design with effective face emissivity ~0.5, isolated telescope column with an 8 W thermostat heater, battery vault heater, survival heaters; electronics -10..33 C, battery 4..15 C (`docs/thermal.md`).

**Attitude and propulsion.** Three reaction wheels, magnetorquers, star tracker; iodine gridded-ion thruster in a bay on the -X centre line with a canted nozzle through the centre of mass; about 570 m/s available, 187 m/s planned (`sim/orbit_life.py`); drag sail (`docs/adcs.md`, `docs/propulsion.md`).

**Compute and firmware.** MSP430FR supervisor, two STM32H7 flight controllers, mass memory unit (8 x 128 GB, 6+2 coding), Pi CM5 and Jetson Orin Nano; host-tested firmware core (auth, modes, FDIR, command queue, OTA), 84 unit checks (`docs/firmware-architecture.md`).

**Communications and protocol.** UHF beacon and LoRa, S-band 250 kbps - 2 Mbps; CCSDS packets with signed telecommands, 27 messages, generated C and Python code with byte-exact tests (`docs/protocol.md`).

**Payload suite.** Telescope with hyperspectral spectrometer, wide-field camera, thermal IR, magnetometer boom, particle spectrometer, X-ray/UV, TSI, GRB, VLF, Langmuir, dosimeter, CSAC, GNSS/TEC, flash and SEU experiments, retroreflector, memory plate, outreach LED (`docs/data-plan.md`).

**Electronics interface.** Notched 100 x 100 mm card, WL-P (2 x 30) and WL-D (2 x 15) connectors at 1.27 mm, passive 15-slot backplane strip per column (KiCad, DRC clean), CANopen-style management over CAN-FD A/B (`docs/electrical-interface.md`).

**Ground and operations.** Reference station at Pamukkale (3.7 passes/day, unattended operation needed), open S-band kit, contact plan tool, commissioning checklist (`docs/ops-concept.md`, `docs/ground-station-kit.md`).

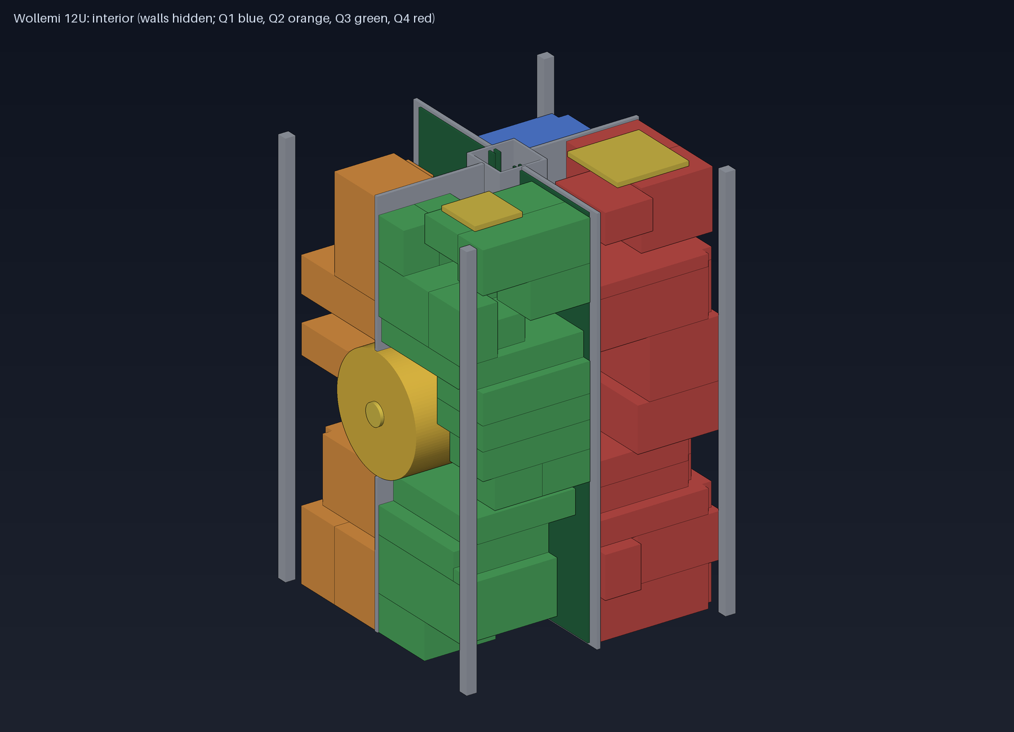
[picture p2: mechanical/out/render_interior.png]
Interior layout


## 5. Decision log (what analysis changed)

| # | Decision | Reason | Triggered by |
|---|---|---|---|
| 1 | 12U form factor, standard CubeSat rails | Sponsors and rideshare providers can only launch what fits a standard dispenser; 12U gave the volume for a science-first payload. | Volume review (6U did not fit: core alone was 159 % of usable volume). |
| 2 | Science-first allocation; hyperspectral shares the telescope optics | Science value drove the payload ranking; sharing the fore-optics saved about 400 cm3. | Volume budget. |
| 3 | Tiered lifetime instead of one 50-year claim | COTS compute and batteries cannot last 50 years; the survival chain and the long-life science chain can. | Longevity analysis (dose, battery cycles). |
| 4 | Long-life science never depends on Linux nodes | Multi-decade records must survive the loss of Jetson and Pi. | Longevity analysis; firmware architecture rule. |
| 5 | Three isolated power paths (A, B, survival C); per-card hardware eFuse, hardware kill | A single fault must not take down the spacecraft; protection must not depend on software. | Power architecture; backplane routing study. |
| 6 | LiFePO4 2S2P 26650 packs (42 Wh each), separated vaults, no wood | Safest lithium chemistry; wood outgasses; real cell data showed 440 g per pack, not 300 g. | EPS design calculation. |
| 7 | Electric iodine propulsion replaced the water resistojet | 12-15x the delta-v for similar volume; enables 50-year station keeping and controlled descent. | Delta-v budget. |
| 8 | Propulsion bay on the -X face centre line with a canted nozzle | A column-mounted nozzle sat ~70 mm from the centre of mass (70 uN m per mN): wheels saturate in minutes; canting also keeps the plume off wing B. | ADCS analysis + CAD geometry. |
| 9 | 1.7 kg tungsten trim ballast | The centre of mass had crept to -18.7 mm in y against a +-20 mm dispenser limit. | CAD mass properties (ICD generation). |
| 10 | Wings must be double-sided; six hold-down posts per wing stack | With the sun on the orbit normal, a single-sided wing faces away; the stowed panel resonated at 99 Hz. | Power scenario review; structural analysis. |
| 11 | Effective face emissivity about 0.5, isolated and heated telescope column, survival heaters | The spacecraft runs cold, not hot: 27 C below the limit with radiator-like faces; the telescope column overheated in sunlit dawn-dusk orbits. | Thermal model. |
| 12 | Wollemi card: 100 x 100 mm with a 20 mm spine notch, 8 mm outer relief, 4 mm backplane gap, 1.27 mm connector pitch | 90 x 90 and 100 x 100 boards could not clear the spine; 0.8 mm pitch could not be routed on the backplane. | Geometric packing; backplane DRC. |
| 13 | Round telescope tube of about 85 mm aperture | A square 100 mm box does not fit around the spine; only a round tube does. | Geometric packing. |
| 14 | OreSat compatibility: CANopen conventions, own connector | Reuse tooling and credit the closest precedent without inheriting a 1U-3U constraint. | Prior-art review. |
| 15 | SCIENCE_LITE mode on the Pi CM5 | The mission simulation showed that imaging stopped forever after a Jetson failure. | Closed-loop mission simulation. |
| 16 | Dawn-dusk sun-synchronous orbit preferred | No eclipse (batteries, thermal swings), best power and burn geometry; fixed wings face the sun. | Power, thermal, ADCS analyses. |
| 17 | Drag sail is required, propulsion descent recommended | From 700 km the sail alone takes 14-20 years on this model, without it 45-50 years. | Orbit lifetime analysis. |
| 18 | Ed25519-signed telecommands, no encryption on the air | Amateur-band rules forbid obscuring meaning; signatures stop forgery and replay. | Protocol design. |
| 19 | FOM-2 and FOM-3 redefined | Wh/U rewarded unused battery; mass spent on safety and longevity is deliberate. | Requirements refresh. |

## 6. Analysis and verification status

- Automatic regression: **23 of 23 checks pass.** (`docs/status.md`).
- Requirements: **47 requirements: 31 PASS (automatic), 0 FAIL, 9 designed but not proven, 7 open.**
- Test plan: 29 planned activities cover the requirements; about 780 engineer-days (`docs/test-plan.md`). No physical test has been done: everything above is analysis and simulation.

## 7. Risks, cost and schedule

Top risks (score = likelihood x impact, `docs/risks.md`):

- **R1** (20): **No launch opportunity or sponsor** (12U rideshare, orbit >= 700 km, cost)
- **R2** (20): **Operator of record, frequency coordination and licensing** not in place (amateur bands, IARU, national authority)
- **R3** (20): **Single-person project scope** (5 processors, 26 instruments, firmware, ground)
- **R4** (20): **Cost** far beyond a hobby budget (cells, thruster, optics, tests)
- **R5** (12): **Double-sided thin wing panels (2.1 mm)** may not meet stiffness, mass or cost (PWR-5)
- **R6** (12): **Residual magnetic dipole > 0.1 A m2** compromises the magnetometer and control

Rough cash cost (USD, unverified +-2x, `docs/cost.md`): Precursor: FlatSat + balloon flight (no launch, no flight-only hardware): P50 0.84 M; Core flight (bus + long-life science chain, no imaging): P50 3.9 M; Full flight (imaging, hyperspectral, extras): P50 4.5 M. Schedule about 4.5 years to launch at the median.

## 8. Open items and decisions for the operator

1. Choose the target: a flight mission, a flight-quality reference design, or the precursor path (FlatSat + balloon); this decides effort and cost by an order of magnitude. *Recommendation (not a decision the design can make): the precursor path first, since it retires the most risk per dollar and keeps the flight-vs-reference choice open until after it.*
2. Confirm the preferred orbit (dawn-dusk sun-synchronous, about 700 km) and whether the outreach LED stays in the flight configuration. *Recommendation: dawn-dusk is favoured on this analysis for thermal, power and battery-life reasons (`docs/orbit-and-debris.md`, `docs/thermal.md`, `docs/longevity.md`) and is the working assumption throughout; the LED is a purely aesthetic choice for the operator, not an engineering one -- the corrected physics (`docs/outreach-led.md`) now shows a blue+violet combination gives both a naked-eye-visible flash and a camera beacon at only 10 W, so cost is no longer a reason against it either way.*
3. Get vendor quotes and datasheets for the thruster, cells, optics and launch; replace estimates and module envelopes.
4. Detailed design still missing: EPS and other schematics, vendor CAD, boom and antenna mechanisms, umbilical and separation switches, finite-element model, thermal detail model.
5. Prior-art and patent search, trademark check for the name, licences and public release (`docs/licensing.md`). *Update: the project was renamed from "Ginkgo" to "Wollemi" after finding that "GINKGO" was a live US trademark (Ginkgo Bioworks, covering computer hardware/software design services) and that a same-named unrelated open-source HPC library already existed; an initial check found no such conflict for "Wollemi", but a full legal clearance search is still needed before any public release (`docs/licensing.md`). Making the repository public is the operator's decision to make and to act on, not something to be done automatically here.*
6. Partners: a licensed operator organisation, a launch sponsor or programme, test facilities.
7. The 50-year design life versus the 25-year disposal guideline (`LONG-4`, `docs/orbit-and-debris.md`): documented here as "the 50-year figure is a platform design life; the operational life of any one flight ends with a disposal manoeuvre inside the guideline (or a documented exception)" -- flagged for the operator to confirm or override, since it affects how the mission is described publicly.

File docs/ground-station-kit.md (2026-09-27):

# Open ground-station kit (draft v0)

Goal: anyone can receive Wollemi's science data and telemetry cheaply. SatNOGS provides the network and
database ([SatNOGS](https://satnogs.org/)) and is primarily VHF/UHF today, with S-band named as a goal, so the
S-band part is where Wollemi adds value. Wollemi's high-rate data (about 134 MB per day at the Pamukkale reference station, see
`docs/data-plan.md`) needs S-band; UHF LoRa only carries about 0.5 MB/day.

## Two station classes

| | **Listener** (UHF/LoRa) | **Science station** (S-band) |
|---|---|---|
| Purpose | Beacon, telemetry, relay messages | Full science data, imaging, CFDP |
| Frequency | 433 MHz amateur band (LoRa) | 2.4 GHz amateur S-band |
| Antenna | Omnidirectional or small Yagi | 0.9-1.2 m dish on an az/el rotator |
| Rate | ~1-5 kbps | 0.25-2 Mbps |
| Hardware | LoRa board (TinyGS-class) + small computer | LNA + filter, down-converter or wideband SDR, rotator, Pi-class computer |
| Rough cost | tens of dollars | on the order of one to a few thousand dollars (estimate, unpriced) |

## S-band link margin (`sim/link_budget.py`, 700 km, 10 degrees elevation, 2 W, 6 dBi patch)

| Dish | 250 kbps | 500 kbps | 1 Mbps | 2 Mbps |
|---|---|---|---|---|
| 0.6 m | +6.6 dB | +3.6 | +0.6 | -2.4 |
| 0.9 m | +10.1 | +7.1 | +4.1 | +1.1 |
| **1.2 m** | +12.6 | +9.6 | **+6.6** | +3.6 |
| 1.8 m | +16.2 | +13.2 | +10.1 | +7.1 |

Reading: a 0.9 m dish supports 500 kbps comfortably, 1.2 m supports the 1 Mbps design rate with margin. (A 0.9 m dish is light enough for a SatNOGS/SATRAN-class open-hardware rotator; the 1.2 m dish that reaches the full 1 Mbps design rate needs the heavier rotator below.)
The spacecraft should support **adaptive rate** (250 kbps to 2 Mbps) so smaller stations still get data.
Assumptions: 150 K system temperature, 6.5 dB required Eb/N0, 3 dB miscellaneous losses; full budget still open.

## Kit components and rough BOM (science station, 1.2 m; unpriced hardware not yet chosen, order-of-magnitude only)

| Item | Class | Rough cost (USD) | Notes |
|---|---|---|---|
| 1.2 m offset mesh dish | Ku/C-band satellite-TV mesh dish, repurposed | 150-400 | widely available secondhand; needs a 2.4 GHz feed |
| 2.4 GHz helical or patch feed | custom or amateur-radio surplus | 50-150 | feed illumination must match the dish f/D |
| Low-noise amplifier (2.4 GHz) | amateur/Wi-Fi-band LNA | 30-100 | noise figure drives the system temperature assumed in the link budget |
| Band-pass filter + bias tee + coax/connectors | | 50-150 | keeps Wi-Fi/ISM interference out |
| Az/el rotator with controller | **SPID BIG-RAS class** (see below; open-source SatNOGS/SATRAN rotators do not hold a 1.2 m dish) | 1500-1700 | 1300 Nm torque, 318 kg load rating, hamlib-compatible |
| Wideband SDR (or down-converter + narrowband SDR) | AD9363-class (e.g. PlutoSDR/LimeSDR family) or a 2.4 GHz down-converter feeding an RTL-SDR-class device | 150-500 | adaptive-rate receiver, Doppler tracking in software |
| Compute (tracking, decode, upload) | Raspberry Pi class | 50-100 | runs `groundstation/predict.py`-derived tracking, the decoder, and upload to the archive |
| Mounts, enclosure, cabling, misc | | 100-300 | weatherproofing for an unattended station |
| **Total, science station** | | **roughly 2200 - 4500** (RF chain ~900-2900 + rotator ~1500-1700) | within `configs/12u_cost.toml` (ground segment, two sites: 6-40 k likely 15 k total) |
| Listener station (UHF/LoRa) | LoRa board + small computer | 30-80 | no dish or rotator |

### Rotator: SatNOGS/SATRAN is the wrong choice here, a heavier commercial unit is needed

The project's own preference (open, reusable, community hardware) points at the SatNOGS rotator or the lighter SATRAN kit (< 200 USD) first, but both are sized for Yagis and light parabolic-grid antennas:
SatNOGS builders report the standard rotator handling a 24 dB parabolic grid antenna without a counterweight, but **failing under the weight and wind load of a 1.2 m dish** (community reports; see
[SatNOGS Rotator v3](https://wiki.satnogs.org/SatNOGS_Rotator_v3)). A dish-class science station therefore needs a heavier-duty unit:

- **Selected reference: SPID BIG-RAS az/el rotator** -- 1300 Nm turning torque, 2712 Nm brake torque, 318 kg vertical load rating, 0.5 deg resolution, about 1250 GBP (~1550 USD) as of March 2026 ([The DX Shop](https://thedxshop.com/product/spid-big-ras-heavy-duty-azimuth-elevation-rotator/)). This is well above the BOM range for the RF chain alone, so the total science-station cost should be read as **roughly 2200-4500 USD** once the rotator is priced in, not 900-2900; `configs/12u_cost.toml`'s 6-40 k (likely 15 k) range for two complete ground sites already covers this.
- **Wind-load sanity check:** a 1.2 m dish has a frontal area of about 1.13 m^2. At a 30 m/s design gust (108 km/h), broadside-on (worst case; Cd ~1.2 for a dish-like flat disc), the wind force is about
  0.5 x 1.225 kg/m^3 x 30^2 x 1.2 x 1.13 m^2 ~ 750 N. For a plausible mount standoff of 0.15-0.3 m, that is a wind torque of roughly 110-225 N m about the elevation axis -- 6-12x below the BIG-RAS's
  1300 Nm rating, so the unit has a large margin even in strong wind; a lighter (and cheaper) SPID RAS or BIG-RAK could also be checked against the same 750 N figure once a real mount geometry exists.
- **Software integration**: the SatNOGS client talks to rotators through `hamlib`, which already supports the SPID protocol and most commercial az/el rotators, so choosing a heavier commercial unit does
  not require new client software -- only a `hamlib` rotctld configuration for the SPID protocol.
- The **listener station** (UHF/LoRa, a small Yagi) stays on the SatNOGS or SATRAN open-hardware rotator; only the S-band science station needs the commercial unit.

- Mechanical: 1.2 m offset mesh dish, az/el rotator with enough torque, printable mounts.
- RF: 2.4 GHz feed, low-noise amplifier, band-pass filter, bias tee, coax; SDR (for example an AD9363-based
  or similar wideband device) or a down-converter feeding a low-cost SDR.
- Compute: Raspberry Pi class, running the receiver, tracking, Doppler correction and upload to the open archive.
- Software: SatNOGS-compatible client plugin (decoder for the Wollemi protocol, CFDP receiver, CCSDS frame
  decoding), open data upload, tracking from orbit elements.
- Documentation: build guide, BOM with sourcing notes, alignment and calibration procedure.
- Reference decoder in Python shared with the flight protocol description (`groundstation/decode.py`, `docs/protocol.md`).

## Pass statistics and Doppler (`groundstation/predict.py`)

Synthetic 700 km dawn-dusk sun-synchronous orbit (RAAN = Sun RA - 90 deg), 10 degrees minimum elevation, 7-30 days. **Reference site: Pamukkale (37.9 N, 29.1 E), the operator's home: 3.7 passes/day, mean 447 s, ~28 min/day contact, about 1.3 high passes (> 40 deg) per day.** Others: Ankara 3.9 passes/day (mean 446 s, ~29 min/day contact), Istanbul 4.0,
Singapore 2.9, Tromso 9.7 (~76 min/day). Doppler at 2.4 GHz reaches about +-54 kHz with a rate of only ~0.6 kHz/s (433 MHz: about +-10 kHz),
so tracking with an ordinary SDR is straightforward. Use real orbit elements once the spacecraft exists.

## Software already in the repository

- `groundstation/predict.py`: pass prediction, Doppler and pass statistics (needs `pip install sgp4`).
- `groundstation/decode.py`: reference decoder for hex packets and `.wpk` archive streams, built on the generated protocol module.
- `groundstation/kaitai/wollemi_protocol.ksy`: a [Kaitai Struct](https://kaitai.io/) decoder covering all 27 messages, generated by `protocol/gen_kaitai.py` (see below).

## Open archive: SatNOGS DB integration (OPEN-2, OPEN-7)

"Anyone can receive it" needs more than a public protocol spec: a station that has never heard of this mission still needs to know how to decode its frames. SatNOGS solves exactly this with two
pieces, both real and already in production for other satellites:

1. **SatNOGS DB** ([db.satnogs.org](https://db.satnogs.org/)): the satellite/transmitter registry. Once the spacecraft has a NORAD ID (post-launch), the mission is registered here with its
   transmitter frequencies, modulation and framing, so every SatNOGS station's scheduler knows to listen for it.
2. **SatNOGS Decoders** ([github.com/librespacefoundation/satnogs-decoders](https://github.com/librespacefoundation/satnogs-decoders)): a shared repository of [Kaitai Struct](https://kaitai.io/)
   (`.ksy`) frame decoders. A satellite operator submits a `.ksy` file describing their telemetry format as a pull request; once merged, **every SatNOGS ground station worldwide automatically
   decodes that satellite's frames** and the decoded fields land in SatNOGS DB's telemetry API (open, CC-BY-SA) -- not just the stations the project itself runs. This is the concrete mechanism
   behind OPEN-7 ("data published continuously in an open archive").

**Status:** `groundstation/kaitai/wollemi_protocol.ksy` covers all 27 messages (`protocol/gen_kaitai.py`, generated from the same `protocol/messages.toml` the C and Python implementations use, so the
three can never silently drift apart), switching on the CCSDS APID in the primary header to pick each message's payload type. Its byte-level model (CCSDS primary header bit-packing, the Wollemi
secondary header, telecommand counter/valid-until/signature placement, every payload field) is verified against the real protocol encoder by `groundstation/kaitai/verify_all_ksy.py` (one real
encoded packet per message, every field checked), which is part of the automatic regression.

**The `.ksy` has also been run through the real, official `kaitai-struct-compiler`** (not just the hand-parser model check above): `groundstation/kaitai/compile_check.py` -- optional, not part of
`tools/check_all.py` since a JVM and the compiler are not a standing dependency of this repository -- downloads/locates `kaitai-struct-compiler` and a JVM, compiles the `.ksy` to a real Python
parser, and round-trips all 27 messages through it. **Confirmed working: kaitai-struct-compiler 0.11, Eclipse Temurin JDK 17, 2026-09-27 -- all 27 messages compiled and decoded correctly.** Re-run
`compile_check.py` after any future change to `protocol/messages.toml` or `protocol/gen_kaitai.py` to reconfirm; it prints `SKIPPED` harmlessly on a machine without Java. What remains before a real
pull request to `satnogs-decoders`: the spacecraft needs real transmitter details (frequency, modulation) to register in SatNOGS DB alongside the decoder, which only exists post-launch.

## Anchor stations (COLAV-4: at least two)

- **Primary anchor:** the operator's home in Pamukkale (Denizli), which doubles as the reference for all budgets.
- **Second anchor (proposed, not yet arranged):** a station about 8-11 hours ahead in longitude gives command opportunities spread through the day rather than clustered in the same local hours as
  Pamukkale. Candidates in decreasing order of ease (existing amateur-satellite or university ground-station communities to approach first): a partner station in **East Asia or Australia/New
  Zealand** (for maximum longitude spread), or, as an easier first step while the mission is small, a second **Turkish or nearby-country** amateur radio club station (faster to arrange, smaller
  longitude spread, still removes the single-point-of-failure risk). This is a partnership to arrange, not a design decision; `mission/traceability.toml` (COLAV-4) marks it open until a real
  second site is named.
- Collision-avoidance commanding needs at least one reliable station with transmit capability (COLAV-1, COLAV-4). The kit therefore also needs a **transmit variant** (licensed operator) and a
  documented process for the operator of record; both anchors should eventually have it so a single station outage does not stop commanding.

## Frequency coordination and licensing: where to start (Turkey, reference site)

- **National society:** Turkiye Radyo Amatorleri Cemiyeti (TRAC) is Turkey's IARU member society and the entry point for amateur-satellite frequency coordination questions and for the operator's own
  amateur radio licence.
- **National regulator:** BTK (Bilgi Teknolojileri ve Iletisim Kurumu) administers spectrum and station licensing in Turkey; an amateur satellite still needs the standard IARU international
  coordination (below) plus whatever domestic filing BTK requires for a transmitting ground station and, separately, for the spacecraft's amateur-satellite service use.
- **International coordination:** the actual satellite frequency assignment is coordinated globally through the **IARU Satellite Adviser** and regional advisory panel (not a national body alone,
  since a satellite's footprint is global); the request process and forms are published at [iaru.org/reference/satellites](https://www.iaru.org/reference/satellites/). This should start as soon as
  the link budget and orbit are stable, well before any hardware is built (`mission/requirements.md`, REG-1).
- None of this has been started; it is a real open item (`REG-1`, `COLAV-1`), not a design task, and is why `docs/risks.md` (R2) rates it high.

## Open items

- RF front end and SDR are chosen at reference-design level (this document); actual purchase needs current availability and a supplier that ships to Turkey.
- Rotator selection is closed at reference-design level for the science station (SPID BIG-RAS class); the listener station keeps the SatNOGS/SATRAN open-hardware rotator. A real mount design (standoff,
  mast, guying) is still needed to replace the order-of-magnitude wind-torque check above.
- Frequency coordination, licensing and the operator-of-record process: entry points identified above (TRAC, BTK, IARU); the actual coordination has not been started.
- Prototype with a spare dish and verify against a known S-band source before finalising the BOM (`GND-01`, `mission/tests.toml`).

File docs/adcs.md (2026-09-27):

# Attitude determination and control (draft v0)

Tool: `python sim/adcs.py` (first-order sizing, inertias from the CAD model); geometry checks from `mechanical/wollemi_cad.py`.

## Sizing results (700 km, deployed inertia about 0.18 / 0.34 / 0.27 kg m2)

| Item | Result |
|---|---|
| Gravity gradient | 2.5e-7 N m |
| Aerodynamic (mean / solar max) | 5.6e-8 / 2.8e-7 N m |
| Solar radiation pressure | 5.3e-7 N m |
| **Residual magnetic dipole 0.1 A m2** | **3.0e-6 N m (dominant)**: magnetometer cleanliness and dipole compensation matter |
| Slew 90 deg in 120 s | 0.15 mN m, 8.9 mN m s |
| Candidate wheels (3 x 30 mN m s, 3 mN m) | torque margin x20, momentum margin x3.4 |
| Magnetorquers 1 A m2 | up to 30 uN m, about 18 uN m average (perpendicular to B only) |
| Telescope IFOV / smear budget | 7.7 urad (5.4 m pixel at 700 km); rate error <= 2.3 mrad/s over 1 ms; jitter <= 2.3 urad |
| Rigid-body wheel jitter | negligible (0.002-0.007 urad); the real risk is structural modes and sensor noise |
| Star tracker 5 arcsec | 17 m on the ground; image registration removes it |

## The thruster line must pass through the centre of mass (design change)

With the nozzle in a column (y = +55 mm) and the centre of mass near y = -16 mm the lever arm was ~70 mm: about **70 uN m of torque at 1.1 mN**, four times
the magnetorquer average, and a wheel saturates in about 7 minutes. Resolution adopted:

1. The propulsion module became a **propulsion bay on the -X face centre line** (y = 0, mid-height; a cylinder along X), reserved as a keep-out in
   columns Q2 and Q3 (`configs/12u_geometry.toml`, `mechanical/pack.py`).
2. The nozzle is **canted** so the thrust line passes through the centre of mass: about -3.9 deg (y) and +5.8 deg (z) with the trimmed centre of mass (it was -8.6 / -2.9 deg before the ballast), thrust loss below 1 %.
3. The same cant tilts the exhaust away from wing B: with a 12 deg plume half-angle the cone no longer reaches wing B (uncanted it would).
4. Requirement: centre of mass known and controlled to +-5 mm. A **1.7 kg tungsten ballast** in the Q2 strip trims the centre of mass from y = -18.7 mm (too close to the +-20 mm dispenser limit) to y = -7.3 mm; the remaining offset is absorbed by the fixed cant; residual torque then ~5 uN m, below the magnetorquer average.
5. Continuous magnetorquer desaturation during burns, and a burn-mode attitude controller (`docs/propulsion.md`).

Deorbit or retrograde burns use a 180 degree yaw flip so the exhaust always leaves through the trailing face.

## Panels must be double-sided (power model assumption made explicit)

In a dawn-dusk orbit the sun sits on the orbit-normal (+Y or -Y) side. The wings stow on the +Y and -Y faces and unfold in opposite directions,
so with cells on one face only, one wing would face away from the sun. The power budgets (`configs/12u_science.toml`, scenarios) count both wings as
lit, which is only true with **cells on both faces of each panel** (2.1 mm total thickness required; stiffness, mass and cost are open issues).
The tumbling case is then even better (a double-sided plate averages twice the projected area).

A vendor search (EnduroSat, AAC Clyde Space PHOTON, DHV Technology) found no off-the-shelf CubeSat panel with cells on both faces of one panel: their "single/double/triple deployable"
naming describes the number of folding hinge segments, not which faces carry cells, because a normal 3-axis-stabilised mission always keeps one face sunward and has no reason to populate
the back. Double-sided cell mounting for this mission's geometry is therefore a **custom requirement with no found commercial precedent**, not a proven off-the-shelf option; it needs a
custom panel design and a vendor quote, and the stiffness question is checked separately in `sim/structure.py` (`docs/structure.md`).

A related but **not equivalent** concept does have real space heritage: **bifacial solar cells** (a single cell responsive to light on either face, first flown on the Soviet Salyut 3/5 space
stations in the 1970s and now mainstream) are a different mechanism from what this design needs -- a bifacial cell is normally used with one face toward the sun and the other picking up
reflected/albedo light onto the *same* output, not two independently populated faces each serving a different, opposite pointing direction. It does not by itself resolve PWR-5, but it does
show that space-qualified double-sided light harvesting is not a new idea. Companies doing custom small-satellite solar work (Rocket Lab space solar, Dhruva Space, DHV Technology, in addition
to EnduroSat and AAC Clyde Space above) are the ones to approach for an actual custom double-sided panel quote; none was confirmed to already offer one.

## Open items

- Full simulation: detumble after separation, sun acquisition, nadir tracking, slews, burn mode with flexible modes.
- Wheel micro-vibration and telescope-tube structural modes (modal analysis).
- Sensor suite trade (star tracker, sun sensors, gyro, magnetometer boom effects on control) and star tracker keep-out angles vs the wings.
- Residual magnetic moment budget (0.1 A m2 is a requirement, not yet a measurement).

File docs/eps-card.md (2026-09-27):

# EPS cards (design specification, draft v0)

Diagram: `electronics/eps_diagram.svg` (generated by `electronics/eps_diagram.py`). Numbers: `sim/eps_design.py`. Interfaces: `docs/electrical-interface.md`.
Floor plan: `electronics/gen_eps_card.py` places every function block below on the real 100 x 100 mm notched Wollemi card outline next to the WL-P connector (`electronics/kicad/wollemi_eps_card.kicad_pcb`
for EPS-A/EPS-B, `wollemi_survival_card.kicad_pcb` for the survival card), DRC clean. This proves the partition *physically fits* the card format; it is still a floor plan of labelled placeholder
blocks, **not a schematic** -- no part numbers are selected and nothing is routed. The parts named as candidates below are categories to be checked against datasheets.

## Partitioning

| Card | Function | Fed from |
|---|---|---|
| **EPS-A** | 3 buck MPPT channels, pack A charger and protection, ideal-diode output to bus A, telemetry MCU with CAN-FD | wing A (3 panels, 10s2p, ~24 W each) |
| **EPS-B** | identical to EPS-A | wing B |
| **Survival card** | pack C charger, direct string path to the supervisor (sun-only mode), two burn-wire drivers with three inhibits | dedicated body string (4s2p, ~9.6 V, 1 A) |

Each chain is electrically and physically independent (separate deck, separate vault). Loss of one EPS card removes half of the solar input and one battery bus only.

## Key requirements and values

| Item | Value | Basis |
|---|---|---|
| MPPT input window | 8 - 40 V | string Vmp 20.7 V hot, cold Voc 34.9 V (`eps_design.py`) |
| MPPT power per channel | 24 W in, ~4.6 A out at 5 V, efficiency >= 95 % | 10s2p panel |
| Battery bus | 5.0 - 7.3 V (2S LiFePO4), nominal 6.4 V | `docs/electrical-interface.md` |
| Charge current | CC-CV to 7.3 V, 3.3 A (C/2) per pack; **no charging below 0 C**; balancing | 26650 cells |
| Discharge protection | fuse + eFuse; trip 1.5x nominal | hardware only |
| OVP / UVP | 7.5 V / 4.6 V comparators independent of the MCU | hardware only |
| Output | ideal diode into the bus (OR-ing) | fault isolation |
| Telemetry | V, I, T per string and pack, over CAN-FD | protocol `hk_power` (`docs/protocol-messages.md`) |
| Survival path | string -> ideal diode -> supervisor, works with dead pack C | sun-only mode (AO-7 style) |
| Burn-wire drivers | 2 channels, three independent inhibits (timer, supervisor, separation switch) | launch-provider style requirement |
| Radiation | TID target 30 krad with the vault (`docs/longevity.md`); latch-up protected rails | COTS with mitigation |

## Candidate parts (v0 selection, real COTS parts against the values above; not yet ordered, verified or radiation-screened)

These replace the earlier generic categories with named parts chosen against real datasheet ranges. Nothing here is final: exact charge/OVP/UVP set-point resistors must be computed from each datasheet's own formula (not repeated here to avoid stating a value that has not been checked against the actual datasheet), and TID/latch-up data for most of these parts is not public and needs a vendor NDA or an independent test.

| Block (floor plan) | Candidate part | Why it fits | What still needs checking |
|---|---|---|---|
| `MPPT_BUCK` x3 (EPS-A/B) | **Analog Devices LT8490** buck-boost MPPT battery charger | VIN 6-80 V covers the panel string (20.7 V hot Vmp to 34.9 V cold Voc); VBAT 1.3-80 V covers the 5.0-7.3 V bus; built-in perturb-and-observe MPPT; CC-CV charge profile set by external resistors; thermistor input gives the "no charge below 0 C" cut-off in hardware, no MCU needed | LT8490's named chemistry presets are SLA/flooded/gel/Li-ion; LiFePO4 is not a named preset, so the CC-CV set-points (3.3 A, 7.3 V float per pack, per `docs/eps-card.md`) must be programmed manually per its resistor-programming formula, checked against the datasheet in hand. TID/SEL data not public. |
| `CHG_BAL` (EPS-A/B) | **TI BQ29209-Q1** 2-series cell automatic balance corrector + OV protection | Matches the pack exactly at 2S (most general-purpose balancer/monitor ICs, e.g. TI's BQ769x0 family, start at 3S and do not cover 2S); works with no host/MCU, matching "hardware-only protection"; the LT8490 units already do the pack-level CC-CV charging, so this device's job is narrowed to per-cell balance correction, which fits its actual function | Balancing current and correction time against our charge current and cycle count; confirm it does not conflict with LT8490's own float regulation. |
| `IDEAL_DIODE` (both cards) | **Analog Devices LTC4359** ideal diode controller (drives an external N-FET) | 4-80 V range covers the 5.0-7.3 V bus with margin; explicitly designed for ORing redundant supplies, which is exactly the A/B bus merge and the survival direct path | External FET R_DS(on) and thermal design once the bus current is pinned down; reverse-transient behaviour under a hard short on one chain. |
| `EFUSE_OVPUVP` (EPS-A/B) | **TI TPS2597x** eFuse, 2.7-23 V, 7 A, resistor-set OVP/UVP | Comfortably covers the 5.0-7.3 V bus and battery currents with margin; OVP/UVP thresholds set by resistor dividers, no MCU in the trip path, matching the hardware-only requirement | Exact trip-point resistors from the datasheet formula; inrush/current-limit behaviour into the ideal-diode stage ahead of it. |
| `TELEM_MCU` (EPS-A/B) | **STMicroelectronics STM32G0B1** (Cortex-M0+, integrated FDCAN) | Native CAN-FD peripheral (matches the CAN-FD control plane already in the architecture), low power, well below the STM32H7 flight controllers in cost and complexity since this is telemetry-only, not protection | This MCU is explicitly outside the protection path (telemetry only); its ADC front end (current-sense amps, thermistor dividers) is not yet designed. |
| `CHG_C` (survival card) | **LT8490 again** (parts commonality with EPS-A/B) | Pack C is now specified as 2S1P (`configs/12u_science.toml`, `docs/power-architecture.md`), matching the A/B bus convention on purpose so the same charger, ideal-diode and eFuse parts can be reused across all three chains -- fewer unique parts to qualify and stock | A ~780 mAh small-format LiFePO4 cell in this capacity class is not yet sourced; the charger set-points still need the datasheet-formula check noted above. |
| `DIRECT_PATH` (survival card) | LTC4359 (same as above) | Same ORing function, string straight to the supervisor, bypassing pack C when it is dead (AO-7-style sun-only mode) | As above. |
| `BURNWIRE1`/`BURNWIRE2` (survival card) | **Discrete circuit, not a single IC**: a logic-level N-channel MOSFET high-side switch, gate-enabled only through a **3-input AND gate** (e.g. a single-gate logic IC such as a 74LVC1G11) wired to the three inhibits (timer, supervisor GPIO, separation switch contact) in series, driving a nichrome wire | This is how CubeSat burn-wire releases are built in practice (a MOSFET switch plus a simple current-setting resistor, not a dedicated "burn-wire IC"); published designs use resistances around 8 ohm and currents around 1.6 A for a nichrome element of this class, which the actual wire and current must be sized against, not assumed | Confirms the "hardware-only, three independent inhibits" requirement directly: none of the three gating signals passes through an MCU that could itself be reprogrammed to enable the burn without all three. Wire gauge/resistance and drive current still need picking for the actual hardware. |
| `TELEM_MCU` (survival card) | **Open design question, not yet decided**: the floor plan places a second STM32G0B1 here, but the survival chain's own supervisor (MSP430FR, elsewhere in the architecture) already exists on this power path -- a simpler, more reliable design may read this card's telemetry directly into the supervisor's own ADC instead of adding a second MCU on the highest-reliability chain. Flagged for the next revision rather than decided here. | | |

None of the above has a confirmed radiation (TID/SEL) qualification; all are COTS parts chosen for spec fit only, consistent with the rest of the design (`docs/longevity.md`, radiation vault around the more critical control electronics).

## Verification (planned)

- Board-level: efficiency sweeps, thermal test, cold-start from a dead pack, fault injection (short on each output, open cell, reversed string).
- System-level (PWR-3): loss of packs A and B leaves supervisor and beacon running from the survival string.
- Environmental: thermal cycling with the modelled temperature swings (`docs/thermal.md`), radiation screening of the controllers.

## Open items

- Floor plan done (`electronics/gen_eps_card.py`, DRC clean); choosing real parts and capturing an actual routed schematic in KiCad is still to do.
- Decide whether pack heaters run from the EPS cards or from local heater cards (thermostat, hardware only).
- Wing harness: connector and hinge routing for double-sided panels.

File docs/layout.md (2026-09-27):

# 12U internal layout (generated)

Generated by `python tools/gen_layout_doc.py` from `mechanical/out/placement.json` (the real packing of `mechanical/pack.py`), the mass properties of the CAD model and the thermal loads of `sim/thermal.py`. Do not edit by hand; the layout intent lives in `configs/12u_layout.toml` and `configs/12u_geometry.toml`.
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

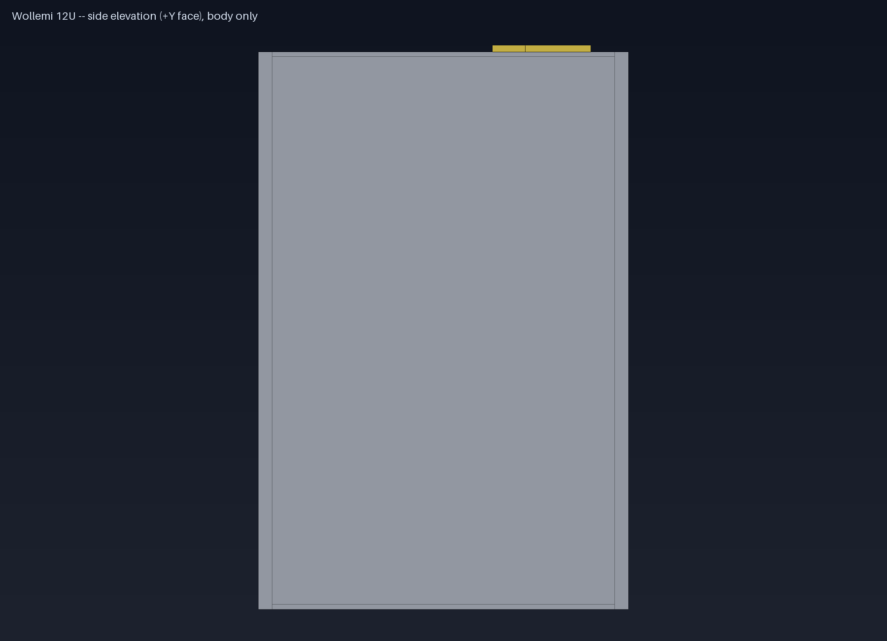
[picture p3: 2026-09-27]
mechanical/out/gallery/ext_side.png

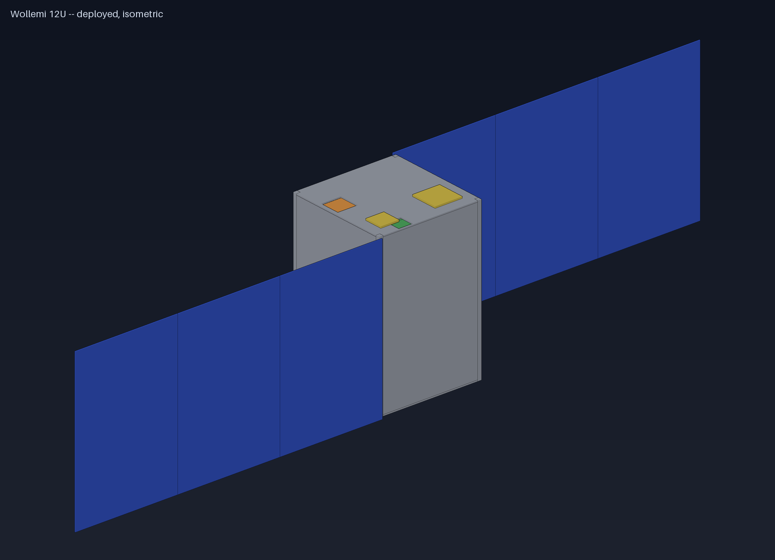
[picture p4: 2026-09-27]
mechanical/out/gallery/ext_iso_deployed.png

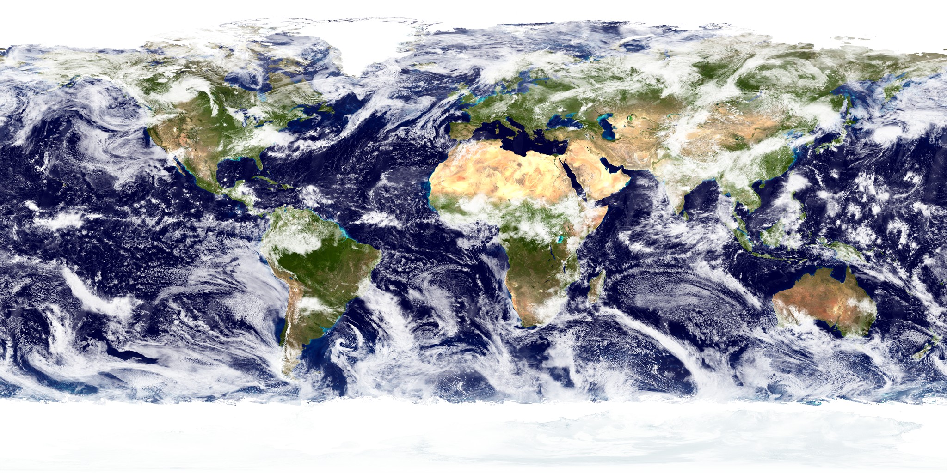
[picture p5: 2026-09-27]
mechanical/blender_assets/earth_bluemarble.jpg

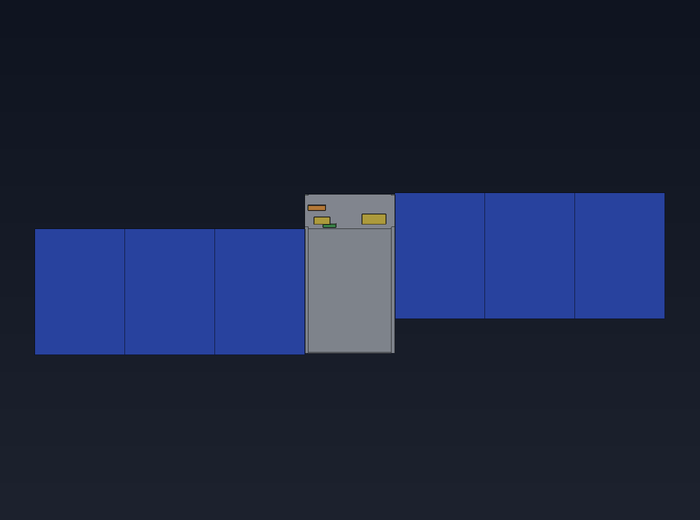
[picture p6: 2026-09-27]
mechanical/out/gallery/spin_deployed.gif

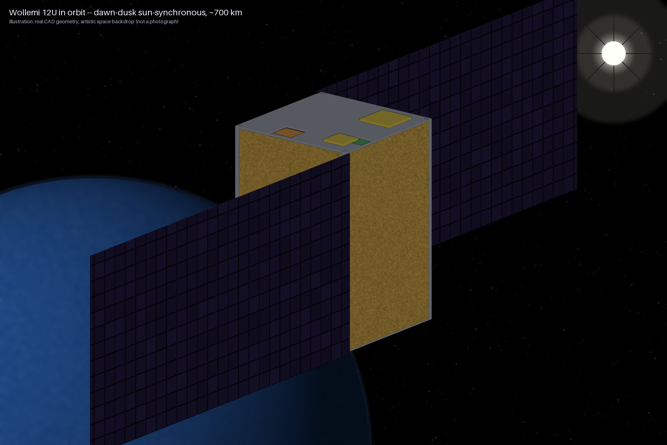
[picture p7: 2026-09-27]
mechanical/out/gallery/space_earth_limb.png

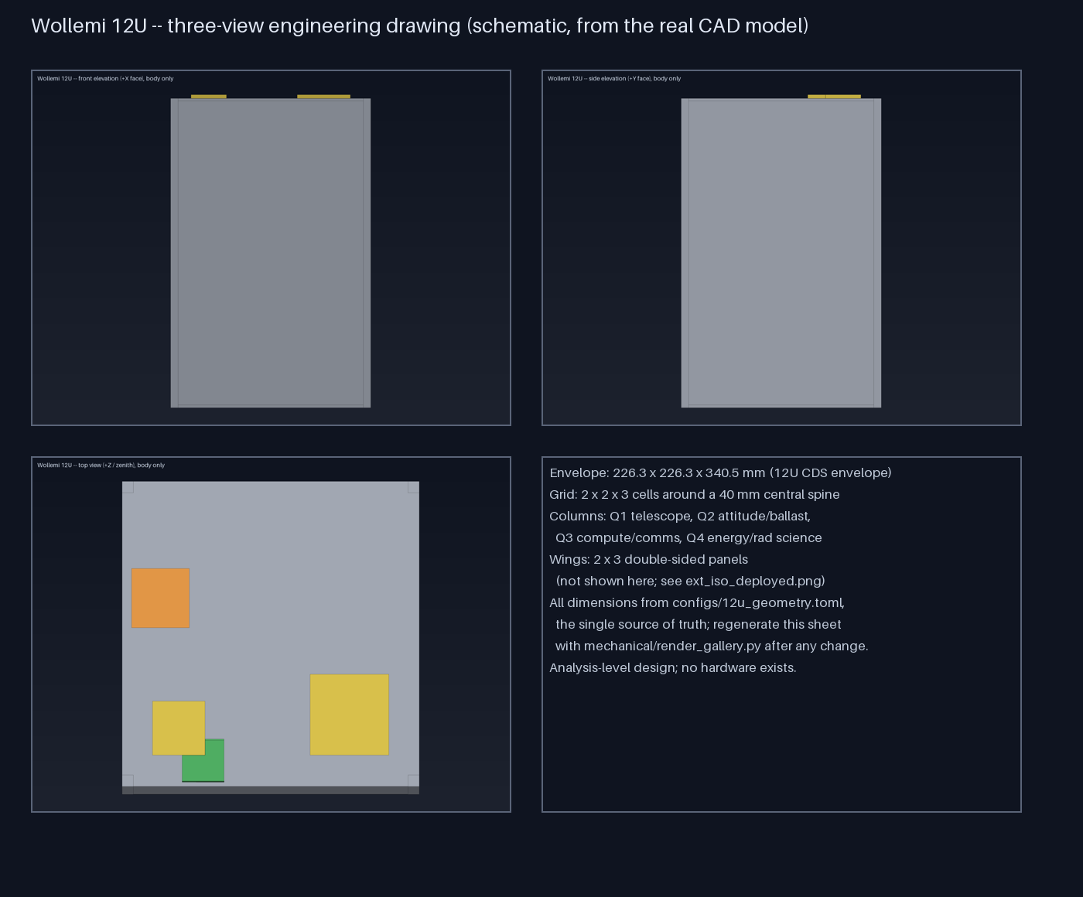
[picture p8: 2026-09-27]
mechanical/out/gallery/three_view_drawing.png

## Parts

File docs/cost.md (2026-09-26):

# Cost and schedule estimate (draft v0)

**Read this first: every number below is an unverified order-of-magnitude estimate made without vendor quotes; treat each as +-2x.** Purpose: to see the scale of the project and which choices drive it, not to
plan a budget. Tool: `python sim/cost.py`; inputs `configs/12u_cost.toml`; test effort from `mission/tests.toml`. Each item is a triangular distribution (low, likely, high) and the totals are Monte Carlo
percentiles (20 000 samples). Labour is shown separately because volunteer time is not cash.

## Scenarios (USD)

| Scenario | Cash P10 | Cash P50 | Cash P90 | Effort (person-years, P50) | Labour value at 90 k per person-year |
|---|---|---|---|---|---|
| **Precursor: FlatSat + balloon flight** (no launch, no flight-only hardware) | 0.72 M | **0.84 M** | 0.97 M | 7.4 | 0.67 M |
| Core flight (bus + long-life science chain, no imaging) | 3.4 M | 3.9 M | 4.4 M | 17.5 | 1.6 M |
| **Full flight** (imaging, hyperspectral, extras) | 4.0 M | **4.5 M** | 5.0 M | 20.3 | 1.8 M |

Schedule to launch (critical path, small team): P10 48 months, **P50 54 months (4.5 years)**, P90 62 months, dominated by long-lead items, the FlatSat and environmental campaign, and the wait for a launch.

## Largest items (likely values)

| Item | Likely cost |
|---|---|
| Launch: 12U rideshare slot with integration | 500 k (250 k - 1.2 M) |
| Electric propulsion (iodine thruster, vendor price unknown) | 380 k |
| Space-weather instruments (particle, X-ray, TSI, GRB, VLF, Langmuir, micrometeoroid) | 220 k |
| Solar wings and body cells (~330 space-grade cells) | 200 k |
| Telescope | 180 k |
| Hyperspectral spectrometer (research level) | 150 k |
| External test facilities (radiation, thermal vacuum, thruster, vibration, EMC) | ~0.7 M (0.35 - 1.4 M) |

Contingency: 30 % on hardware, 15 % on services and tests. Engineering effort excludes the test campaigns (counted from the test plan, `docs/test-plan.md`).

## What this tells us

- A flight of this design is a **multi-million-dollar, multi-year programme**, far beyond hobby scale. Even the cheapest credible flight (core, no imaging) costs about 3.9 M cash.
- The **precursor path** (FlatSat, balloon flight, ground station, the open design and the verified tooling) costs about 0.8 M in cash at these assumptions and is mostly labour; it retires most software, electronics and link
  risk and is the natural first stage for sponsors and partners. Much of it can be reduced further with volunteers and donated parts.
- Cost drivers to attack first: launch price (rideshare aggregators, university programmes), the thruster (a decision on whether a lighter, cheaper propulsion option meets the mission), solar cell count (single-sided or
  smaller wings), the number of science instruments (research-level ones are optional), and test facilities (share campaigns with partners, use university facilities).
- Reducing scope is the strongest lever: dropping imaging saves about 0.6 M, dropping the propulsion and its consequences (disposal, collision avoidance) would save about 0.4-0.7 M but conflicts with the 25-year disposal
  guideline at 700 km unless the orbit is lower (`docs/orbit-and-debris.md`).

## Assumptions and limits

- No vendor quotes; several items (thruster, hyperspectral, GRB detector, TSI radiometer) could be off by more than 2x.
- Labour value at 90 000 USD per person-year is a professional rate; volunteers and partners change the cash needed but not the effort.
- Launch prices vary widely with provider, orbit and date; a dawn-dusk sun-synchronous slot at 700 km may cost more than a mid-inclination slot.
- Not included: cost of failure (a second unit), insurance beyond the allowance, taxes and import duties, currency effects, cost of the science analysis after launch, and operations over decades
  (about one to two people plus ground stations; not modelled).
- The FlatSat is assumed at 40 % of core electronics hardware cost; the balloon flight at 8-30 k.

## Next

- Ask vendors for indicative quotes (thruster, cells and panels, optics, launch aggregators) and replace the ranges.
- Build the scenario table for the sponsor brief (`docs/sponsor-brief.md`, to be written) with the precursor as stage one.

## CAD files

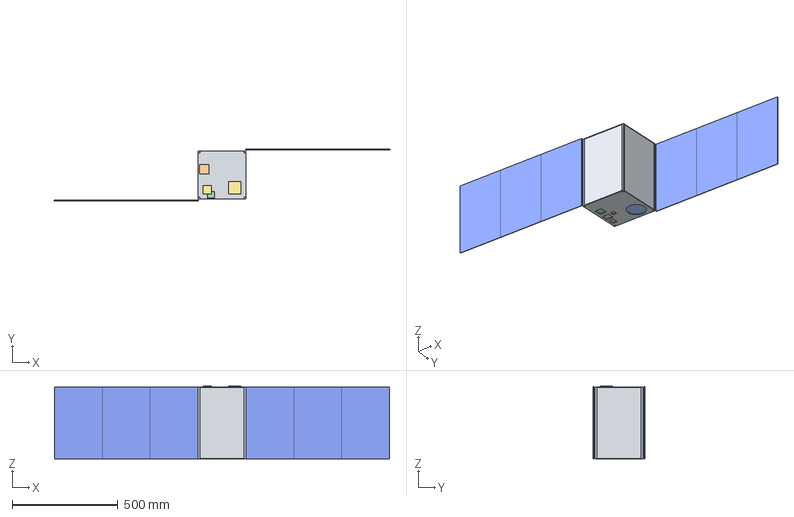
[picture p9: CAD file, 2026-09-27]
mechanical/out/wollemi_12u_deployed.step
1584.1 x 243.5 x 344.5 mm
Rail +1+1
Rail +1-1
Rail -1+1
Rail -1-1
Wall +X
Wall -X
Wall +Y
Wall -Y
Nadir plate
Zenith plate
GNSS patch antenna
S-band patch antenna
Backplane strip Q1
Backplane strip Q2
Backplane strip Q3
Backplane strip Q4
Spine tube
Bulkhead X
Bulkhead Y+
Bulkhead Y-
Thruster nozzle
Bus: micro-propulsion (electric, iodine gridded-ion class, m
Payload E: telescope camera (85 mm Cassegrain, ~5 m GSD at 7
Bus: star tracker (dedicated)
Payload F: wide-field camera / star tracker
OUTREACH: RGB LED flasher (violet 405 nm main + red + blue,
Payload G: thermal IR imager (160x120 microbolometer)
SCI: deployable magnetometer boom (low-noise, away from elec
Antenna + deploy mech
Payload H: dual-frequency GNSS (position + ionosphere TEC)
EO: lightning / optical transient detector
EO: hyperspectral spectrometer (shares telescope fore-optics
ADCS: 3 reaction wheels + torquers + sensors
SCI: gamma-ray burst detector (CsI + SiPM)
Mission computer: Jetson Orin Nano (Linux, GPU) + conductive
Battery containment: alu box + polyimide/ceramic barrier + h
SCI: energetic particle spectrometer (e-/p+)
LiFePO4 pack A (2S2P 26650, 42 Wh) + BMS + fuse
LiFePO4 pack B (2S2P 26650, 42 Wh) + BMS + fuse
Bus: drag sail (passive deorbit backup)
SCI: VLF/ELF receiver (whistlers, lightning, E-field)
EPS board
EPS board B (redundant) + ideal-diode OR-ing
SCI: total solar irradiance radiometer (climate-grade, long
S-band transceiver (high-rate downlink, RX)
SCI: Langmuir probe (plasma density, boom)
Mission computer B: Raspberry Pi CM5 (always-on, low power,
SCI: solar X-ray / UV monitor (flare detection)
Mass memory unit: 8 x 128 GB eMMC/SLC, 6+2 erasure coding, a
Survival bus: containment + isolated charger + burn-wire dep
UHF LoRa comms (RX)
S-band transceiver (TX)
LONG: impact protection (double-wall Whipple-type, Nextel/Ke
LONG: radiation vault (graded-Z Al/Ta box, ~10 mm Al-eq) aro
LONG: CoM trim ballast (tungsten, 1.7 kg) in the Q2 strip
Flight controller (STM32H7 x2) + watchdog (MSP430FR)
LiFePO4 pack C (2S1P, 5 Wh, 6.4 V nominal, ~780 mAh) surviva
Payload B: magnetometer + sun sensors
Payload A: SEU experiment
Payload D: store-and-forward relay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

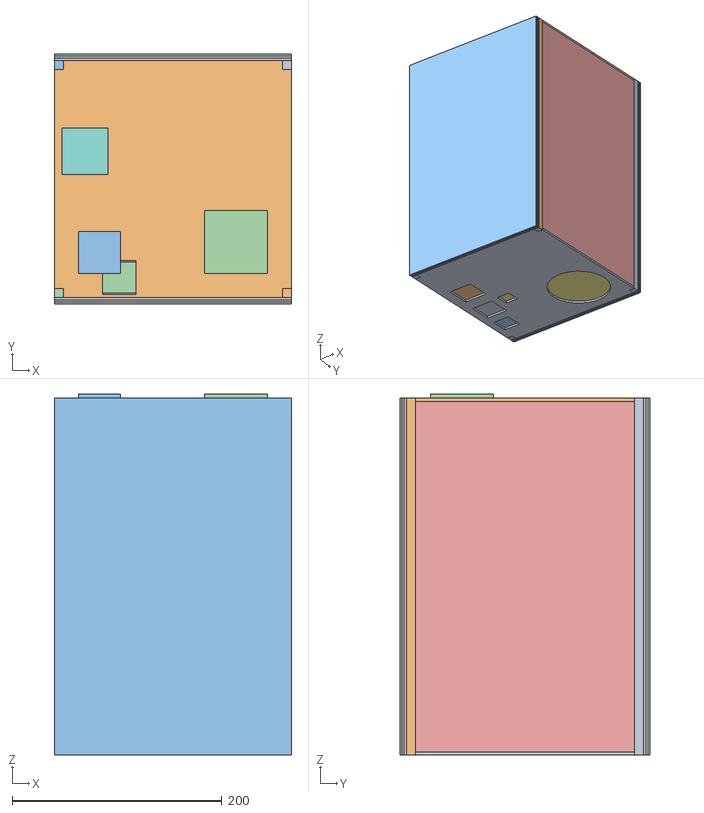
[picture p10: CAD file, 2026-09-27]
site/assets/model/wollemi_stowed.obj
226.3 x 238.9 x 344.5
part_0_Rail__1_1
part_1_Rail__1_1
part_2_Rail__1_1
part_3_Rail__1_1
part_4_Wall__X
part_5_Wall__X
part_6_Wall__Y
part_7_Wall__Y
part_8_Nadir_plate
part_9_Zenith_plate
part_10_GNSS_patch_antenna
part_11_S_band_patch_antenna
part_12_Backplane_strip_Q1
part_13_Backplane_strip_Q2
part_14_Backplane_strip_Q3
part_15_Backplane_strip_Q4
part_16_Spine_tube
part_17_Bulkhead_X
part_18_Bulkhead_Y_
part_19_Bulkhead_Y_
part_20_Thruster_nozzle
part_21_Bus__micro_propulsion__electric__iodine_
part_22_Payload_E__telescope_camera__85_mm_Casse
part_23_Bus__star_tracker__dedicated_
part_24_Payload_F__wide_field_camera___star_trac
part_25_OUTREACH__RGB_LED_flasher__violet_405_nm
part_26_Payload_G__thermal_IR_imager__160x120_mi
part_27_SCI__deployable_magnetometer_boom__low_n
part_28_Antenna___deploy_mech
part_29_Payload_H__dual_frequency_GNSS__position
part_30_EO__lightning___optical_transient_detect
part_31_EO__hyperspectral_spectrometer__shares_t
part_32_ADCS__3_reaction_wheels___torquers___sen
part_33_SCI__gamma_ray_burst_detector__CsI___SiP
part_34_Mission_computer__Jetson_Orin_Nano__Linu
part_35_Battery_containment__alu_box___polyimide
part_36_SCI__energetic_particle_spectrometer__e_
part_37_LiFePO4_pack_A__2S2P_26650__42_Wh____BMS
part_38_LiFePO4_pack_B__2S2P_26650__42_Wh____BMS
part_39_Bus__drag_sail__passive_deorbit_backup_
part_40_SCI__VLF_ELF_receiver__whistlers__lightn
part_41_EPS_board
part_42_EPS_board_B__redundant____ideal_diode_OR
part_43_SCI__total_solar_irradiance_radiometer__
part_44_S_band_transceiver__high_rate_downlink__
part_45_SCI__Langmuir_probe__plasma_density__boo
part_46_Mission_computer_B__Raspberry_Pi_CM5__al
part_47_SCI__solar_X_ray___UV_monitor__flare_det
part_48_Mass_memory_unit__8_x_128_GB_eMMC_SLC__6
part_49_Survival_bus__containment___isolated_cha
part_50_UHF_LoRa_comms__RX_
part_51_S_band_transceiver__TX_
part_52_LONG__impact_protection__double_wall_Whi
part_53_LONG__radiation_vault__graded_Z_Al_Ta_bo
part_54_LONG__CoM_trim_ballast__tungsten__1_7_kg
part_55_Flight_controller__STM32H7_x2____watchdo
part_56_LiFePO4_pack_C__2S1P__5_Wh__6_4_V_nomina
part_57_Payload_B__magnetometer___sun_sensors
part_58_Payload_A__SEU_experiment
part_59_Payload_D__store_and_forward_relay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

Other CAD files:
mechanical/out/wollemi_12u_stowed.step
site/assets/model/wollemi_deployed.obj
mechanical/out/ginkgo_12u_stowed.step
mechanical/out/ginkgo_12u_deployed.step
mechanical/out/wollemi_12u_deployed.stl
mechanical/out/wollemi_12u_stowed.stl

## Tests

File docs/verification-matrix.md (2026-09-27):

# Verification matrix (generated)

Generated by `python sim/trace_check.py` from `mission/traceability.toml`; numeric checks run on the real design data.

**47 requirements: 31 PASS (automatic), 0 FAIL, 9 designed but not proven, 7 open.**

| ID | Method | Status | Requirement | Evidence / result |
|---|---|---|---|---|
| SYS-1 | I | DESIGNED | 12U CubeSat envelope (226.3 x 226.3 x 340.5 mm) with rails; deployer interface compatible. | Rails and envelope modelled; dispenser tabs, springs and contact surfaces simplified: check against the chosen dispenser drawing. (`mechanical/wollemi_cad.py`, `configs/12u_geometry.toml`) |
| SYS-2 | A | PASS | Total mass <= 24 kg (deployer limit); planned margin >= 20 % (<= 19 kg). | 16.75 kg of 24 kg; margin 13 % against 19.2 kg (80 % of the limit) (`sim/budget.py`, `configs/12u_science.toml`) |
| SYS-3 | A | PASS | All modules fit geometrically inside their assigned columns with no interference (exact boolean check). | 48 modules placed, 0 failed, 0 relocated (`mechanical/pack.py`, `mechanical/wollemi_cad.py`) |
| SYS-4 | A | PASS | Centre of mass within 20 mm (x, y) and 70 mm (z) of the geometric centre at launch. | CoM (-5.8, -7.3, +10.8) mm (`mechanical/wollemi_cad.py`) |
| SYS-5 | A | PASS | Stowed wing stack thickness <= 6.5 mm protrusion allowance. | 6.30 mm vs 6.5 mm (`configs/12u_geometry.toml`) |
| STR-1 | A | PASS | Fundamental frequencies of the frame, side walls and stowed wing panels >= 100 Hz; all structural margins >= 1 at the design load factor (hand analysis). | Verdict: 16 of 16 structural checks meet their margin. (`sim/structure.py`, `configs/12u_structure.toml`, `docs/structure.md`) |
| PWR-1 | A | PASS | Orbit-average power margin >= 20 % in every power scenario (nominal, tumbling, dawn-dusk, safe, burn). | worst scenario 'Typical LEO, tumbling, wings deployed' margin +36 % (`sim/budget.py`) |
| PWR-2 | A | PASS | Eclipse energy covered by the usable battery capacity with margin >= 2x. | usable 34 Wh vs worst need 12.2 Wh (x2.7) (`sim/budget.py`) |
| PWR-3 | T | DESIGNED | An independent survival power path (pack C, own string and charger) keeps supervisor and beacon alive when packs A and B are lost. | Needs an electrical test of fault injection on the EPS engineering model. (`docs/power-architecture.md`) |
| PWR-4 | A | PASS | Solar string voltages stay inside the MPPT input window over the temperature range. | cold Voc 34.9 V < 40 V input limit: OK; hot Vmp 20.7 V > 8 V: OK (`sim/eps_design.py`) |
| PWR-5 | I | OPEN | Wing panels carry cells on both faces (needed for the dawn-dusk power scenarios). | A vendor search found no off-the-shelf double-sided panel (EnduroSat/AAC Clyde/DHV all single-faced); custom panel and vendor quote needed. Stiffness is checked (sim/structure.py, 1.4x margin on a conservative estimate); mass and cost are still unproven. (`docs/adcs.md`, `mechanical/README.md`, `docs/structure.md`) |
| THM-1 | A | PASS | Electronics stay within -20..+60 C in nominal and eclipse orbits; battery within 0..40 C. | electronics -5..34 C, battery 4..18 C (nominal, eclipse and safe cases) (`sim/thermal.py`, `configs/12u_thermal.toml`) |
| THM-2 | A | PASS | Telescope column 10..30 C with swing <= 6 K while imaging. | nom80: 26..27 C (swing 0.7 K); nom0: 13..18 C (swing 4.4 K) (`sim/thermal.py`) |
| ADCS-1 | A | PASS | 90 degree slew in 120 s with torque and momentum margin >= 3x. | torque margin x20, momentum margin x3.4 (`sim/adcs.py`) |
| ADCS-2 | A | PASS | Thruster misalignment torque during a burn stays below the magnetorquer average torque (thrust line through the CoM +-5 mm). | uncanted 14 uN m; with the fixed cant (-4.0, 6.0 deg) and a 5 mm CoM uncertainty 5.5 uN m < 18 uN m magnetorquer average (`mechanical/wollemi_cad.py`, `docs/adcs.md`) |
| PROP-1 | A | PASS | Total delta-v >= 500 m/s (station keeping to ~700 km, collision avoidance, controlled deorbit). | 567 m/s from a 9500 Ns class thruster at 16.8 kg (vendor class value, unverified); plan (50 yr keeping x1.5, descent, avoidance) 187 m/s (`docs/propulsion.md`) |
| PROP-2 | A | PASS | Exhaust plume clear of the solar wings. | cone edge meets the wing B plane at x = -952 mm (wing ends at -792 mm): clear (`mechanical/wollemi_cad.py`) |
| ORB-1 | A | PASS | At end of life the spacecraft can reach reentry within 25 years: passive with the drag sail, plus a propulsive descent option; total delta-v plan within the available budget. | Verdict: at 700 km the sail alone gives 14-20 years (meets 25 years on this model, with a factor 2-3 uncertainty), witho (`sim/orbit_life.py`, `docs/orbit-and-debris.md`) |
| COM-1 | A | PASS | One S-band station at the reference site (Pamukkale) receives all daily science data with >= 2x margin. | capacity 134 MB/day vs science + reserve 49 MB/day (x2.8) (`sim/data_budget.py`, `configs/12u_data.toml`) |
| COM-2 | A | PASS | S-band link margin >= 3 dB at 1 Mbps with a 1.2 m ground dish at 10 degrees elevation. | +6.6 dB (`sim/link_budget.py`) |
| COM-3 | T | PASS | Packet encode/decode is bit-exact between flight (C) and ground (Python) and rejects every single-bit corruption. | ALL PASSED (`protocol/tests/test_protocol.py`) |
| COM-4 | T | PASS | Telecommands carry a valid Ed25519 signature, counter and validity window; the supervisor rejects others (replay, expired, forged, tampered, bad CRC). | firmware core: 84 checks, 0 failures; authentication cross-checks: 11/11 OK (`firmware/common/wl_auth.c`, `firmware/tests/run_tests.py`) |
| FW-1 | T | PASS | Mode manager, FDIR escalation, time-tagged command queue and A/B OTA with rollback behave as specified (84 unit checks, gcc -Werror), including SCIENCE_LITE when the heavy computer is lost. | firmware core: 84 checks, 0 failures; authentication cross-checks: 11/11 OK (`firmware/common/wl_modes.c`, `firmware/common/wl_fdir.c`, `firmware/common/wl_cmdq.c`, `firmware/common/wl_ota.c`) |
| DATA-1 | A | PASS | On-board storage holds >= 100 days of raw data and tolerates any two device failures. | 163 days of raw data, 2 parity devices (`sim/data_budget.py`, `docs/firmware-architecture.md`) |
| LONG-1 | T | DESIGNED | Survival chain (supervisor + beacon) operates from body cells without any battery (sun-only mode). |  (`docs/longevity.md`, `docs/power-architecture.md`) |
| LONG-2 | A | PASS | Long-record science instruments never depend on Linux nodes for acquisition or downlink. | CHAIN CHECK OK: 14 long-life streams acquired by the flight controller and stored via the mass memory unit; 3 streams may use the Linux computers (`sim/chain_check.py`, `configs/12u_data.toml`, `docs/firmware-architecture.md`) |
| LONG-3 | A | PASS | Main packs still cover eclipse after 10 years in an eclipse orbit (a dawn-dusk orbit has none); safe-mode power holds for 50 years (with the modelled degradation). | main packs cover eclipse for ~10 yr; safe mode holds 90.8 yr (`sim/longevity.py`) |
| SIM-1 | A | PASS | Closed-loop simulation of the real mode manager over 60 days with injected faults shows no brownout and correct degradation and recovery in a typical and a dawn-dusk orbit. | Verdict: closed-loop simulation with the real mode manager: no brownout, correct degradation and recovery in both orbits (`sim/mission_sim.py`, `firmware/common/wl_modes.c`, `docs/mission-simulation.md`) |
| FMEA-1 | A | PASS | FMEA covers all subsystems; every failure mode of severity >= 4 has a detection and a response from the FDIR vocabulary. | FMEA coverage OK: 42 failure modes, 10 subsystems, 19 with severity >= 4 fully covered; wrote docs/fmea.md (`mission/fmea.toml`, `tools/fmea_check.py`, `docs/fmea.md`) |
| ELEC-1 | A | PASS | Card template passes KiCad DRC with the spine notch, connectors and keep-outs defined. | Found 0 DRC violations (`electronics/gen_card.py`, `electronics/kicad/wollemi_card_template.kicad_pcb`) |
| ELEC-2 | A | PASS | Column backplane strip (15 slots + hub, bussed CAN/PPS/SYNC/SLOT_SEL/KILL/FAULT/RESET/I2C, GND and battery planes) passes DRC with zones refilled and no unconnected items. | Found 0 DRC violations, 0 unconnected pads (`electronics/gen_backplane.py`, `electronics/kicad/wollemi_backplane_strip.kicad_pcb`) |
| ELEC-3 | A | PASS | EPS cards specified (A/B chains and survival chain, hardware-only protection); schematics captured. | wollemi_eps_card: 0 violations; wollemi_survival_card: 0 violations (`docs/eps-card.md`, `electronics/eps_diagram.svg`, `electronics/gen_eps_card.py`) |
| OPEN-1 | I | OPEN | All design files, data and protocol are public under open licences (hardware CERN-OHL-S, software Apache-2.0, docs CC-BY). | Repository is private until the design is complete; licence files are not applied yet. (`README.md`) |
| COLAV-1 | D | OPEN | Operator of record registered for conjunction data messages; collision-avoidance burns validated on the ground. | Needs a licensed operator and registration; process not started. (`mission/requirements.md`) |
| REG-1 | I | OPEN | Frequency coordination and amateur-satellite licensing completed before launch. |  (`mission/requirements.md`) |
| COLAV-2 | A | PASS | Avoidance burns are uploaded 24-48 h ahead (propulsion, stable attitude and about 53 W available during the burn). | burn-mode load 53 W (thruster, minimal services) against about 94 W instantaneous sunlit generation (+77 %) in the sun-biased attitude (`sim/budget.py`, `sim/eps_design.py`) |
| COLAV-3 | I | DESIGNED | Precise orbit knowledge: dual-frequency GNSS plus laser retroreflector; GNSS-derived ephemerides shared with tracking services. | GNSS receiver and retroreflector are in the module list; accuracy needs a receiver test (GND/SYS tests). (`configs/12u_science.toml`) |
| COLAV-4 | D | OPEN | At least two reliable anchor ground stations guarantee command opportunities at least daily; the volunteer network supplements them. | The reference station at Pamukkale exists only as a plan; a second anchor site is not yet identified. (`docs/ground-station-kit.md`, `groundstation/contact_plan.py`) |
| COLAV-5 | I | DESIGNED | Impact detection is for science and status only; small untracked debris is countered by design margin, not avoidance. |  (`docs/orbit-and-debris.md`) |
| COLAV-6 | A | PASS | Passivation and end-of-life: propulsive descent or drag sail; propellant reserve kept for disposal. | 567 m/s from a 9500 Ns class thruster at 16.8 kg (vendor class value, unverified); plan (50 yr keeping x1.5, descent, avoidance) 187 m/s (`sim/orbit_life.py`, `docs/orbit-and-debris.md`) |
| LONG-4 | D | OPEN | Disposal versus 50 years: the operational life ends with a disposal manoeuvre (or a documented exception) within the 25-year guideline; the 50-year tier is a platform design life. | Policy decision: which of the two goals the flight article follows. (`docs/orbit-and-debris.md`) |
| OPEN-2 | I | OPEN | Once launched, the spacecraft is open to everyone: anyone with a low-cost station can receive telemetry and payload data. | Depends on launch and licensing. (`docs/protocol.md`, `docs/link-budget.md`) |
| OPEN-3 | I | DESIGNED | Public relay service: any licensed amateur can send and fetch short messages through the store-and-forward payload. | Policy written (docs/relay-policy.md); the ground ingestion service it specifies is not yet built. (`docs/protocol.md`, `docs/relay-policy.md`) |
| OPEN-4 | I | DESIGNED | All downlinked data is unencrypted and the protocol is fully documented (amateur-band rule: no obscured meaning). | Protocol is fully specified in protocol/messages.toml; nothing is encrypted. (`docs/protocol.md`, `protocol/messages.toml`) |
| OPEN-5 | I | DESIGNED | Only spacecraft control commands are authenticated (signed, not encrypted); public relay traffic needs no key. | Signature check is implemented and tested (firmware/tests). (`firmware/common/wl_auth.c`) |
| OPEN-6 | I | DESIGNED | Rate limits and message quotas protect the relay from flooding; policy documented. | Quotas specified (5 msg/callsign/day, 256-message onboard queue, FIFO drop, 7-day expiry); ground ingestion service and onboard queue enforcement not yet built. (`docs/relay-policy.md`) |
| OPEN-7 | A | PASS | Data published continuously in an open archive (for example SatNOGS DB). | all 27 messages' .ksy byte-model match the real encoder (`docs/ground-station-kit.md`, `groundstation/kaitai/wollemi_protocol.ksy`, `groundstation/kaitai/verify_all_ksy.py`, `protocol/gen_kaitai.py`) |

Methods: A analysis, T test, I inspection, D demonstration. PASS means the automatic check passes on the current design; it is an analysis result, not a substitute for test.

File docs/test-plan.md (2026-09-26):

# Verification and test plan (generated)

Source: `mission/tests.toml` against `mission/traceability.toml`; generated and checked by `python tools/test_plan_check.py`. Effort figures are estimates in engineer-days for one campaign.

29 planned activities, 47 requirements covered by tests, 3 waived (analysis only, with a reason); 0 uncovered. Total effort about 780 engineer-days (about 3.5 person-years), of which 315 days involve medium/high-cost external facilities.

## Approach

1. Verify by analysis first (the automatic checks of `sim/trace_check.py`), then confirm with test at the lowest level where the risk can be retired.
2. Build the integrated **FlatSat** early: it exercises the electronics, firmware, protocol and mission simulation on real hardware long before flight hardware exists.
3. A **high-altitude balloon** precursor flies the computers, cameras, LoRa/GNSS and the ground chain (`PRE-01`), retiring software and link risk cheaply.
4. Environmental tests (vibration, shock, thermal vacuum, EMC, battery safety) use the launch provider's levels; qualification level and acceptance level are decided with the provider.
5. Every severity >= 4 failure mode of the FMEA is injected on the FlatSat (`SYS-03`).

## Test list

### Component

| ID | Activity | Covers | Method | Days | External |
|---|---|---|---|---|---|
| CMP-01 | Battery pack cell and pack tests (capacity, DoD cycling at the LEO profile, vent and short tests in the vault) | PWR-2, PWR-3, LONG-3 | T | 40 | low |
| CMP-02 | Solar cell and double-sided panel coupon tests (I-V at temperature, thermal cycling, bending and vibration of a 2.1 mm panel) | PWR-4, PWR-5, STR-1, SYS-5 | T | 30 | medium |
| CMP-03 | Radiation screening of COTS parts: total dose (control electronics, radios, flash) and single-event/latch-up (Jetson, CM5, MCUs) | LONG-1, LONG-2, LONG-3 | T | 25 | high |

### Board

| ID | Activity | Covers | Method | Days | External |
|---|---|---|---|---|---|
| BRD-01 | Card template and backplane bring-up: fit check of notched cards in a 3D-printed column, continuity of every backplane net, DRC-to-fab check | ELEC-1, ELEC-2, SYS-3 | T | 15 | low |
| BRD-02 | EPS card engineering models: MPPT efficiency, cold start from a dead pack, charge control limits, OVP/UVP, eFuse trips, survival path with pack C removed | ELEC-3, PWR-3, PWR-4, PWR-1 | T | 45 | none |
| BRD-03 | Supervisor and hardware kill: SLOT_SEL/KILL_N latch-off of a card, watchdog and beacon on the survival string alone | PWR-3, LONG-1, ELEC-1 | T | 20 | none |

### Subsystem

| ID | Activity | Covers | Method | Days | External |
|---|---|---|---|---|---|
| SUB-01 | Telecommand authentication on the target processors: signature, replay, expiry, key rotation, timing of Ed25519 verify | COM-4 | T | 10 | none |
| SUB-02 | Packet and CFDP stack on target hardware with the ground decoder: bit-exactness, corruption, loss and resume across passes | COM-3, DATA-1 | T | 20 | none |
| SUB-03 | Mass memory unit: erasure-coding stress, device failure injection (two devices), scrubbing, power-loss safety, data volume for 100 days of raw data | DATA-1 | T | 25 | none |
| SUB-04 | ADCS bench: wheels, torquers, sensors on an air-bearing or torsion table; slew and momentum dumping; magnetic moment measurement | ADCS-1, ADCS-2 | T | 40 | medium |
| SUB-05 | Iodine thruster with the spacecraft bay: thrust and plume measurement, thermal behaviour, contamination witness plates, canted mount alignment | PROP-1, PROP-2, ADCS-2, THM-1 | T | 40 | high |
| SUB-06 | Telescope and hyperspectral optics: focus, MTF, thermal focus shift, ground sample distance on a collimator or a distant target | THM-2 | T | 35 | medium |
| SUB-07 | Wing deployment and hold-down: burn-wire release repeatability, deployment shock, hinge torque, stowed frequency of the stack | SYS-5, STR-1, PWR-5 | T | 30 | low |

### System

| ID | Activity | Covers | Method | Days | External |
|---|---|---|---|---|---|
| SYS-01 | FlatSat integration: all cards, computers, sensors and radios on a bench with a simulated power and orbit environment; mission simulation replayed on hardware | SYS-3, PWR-1, PWR-2, COM-3 | T | 90 | none |
| SYS-02 | Hardware-in-the-loop mission run (60 days compressed): mode manager, FDIR, command queue, OTA with real processors and timing | SIM-1, FW-1 | T | 30 | none |
| SYS-03 | Fault injection campaign from the FMEA: each severity >= 4 failure mode injected and the response verified | FMEA-1, PWR-3, LONG-2 | T | 30 | none |
| SYS-04 | Mass properties on the flight model: mass, centre of mass and moments of inertia measured against the CAD values | SYS-2, SYS-4, ADCS-2 | T | 5 | low |
| SYS-05 | Magnetic cleanliness survey: residual dipole of the flight model with the boom stowed and deployed | ADCS-2 | T | 10 | medium |
| SYS-09 | Precise orbit knowledge: GNSS receiver accuracy on a hardware simulator or balloon flight, retroreflector ranging campaign plan with a laser station | COLAV-3 | T | 20 | medium |

### Environmental

| ID | Activity | Covers | Method | Days | External |
|---|---|---|---|---|---|
| ENV-01 | Vibration: sine sweep for modes, random at the launch provider's levels, quasi-static; before and after signatures | STR-1, SYS-1, SYS-5 | T | 10 | medium |
| ENV-02 | Shock: separation and deployment shock levels on the flight model | STR-1 | T | 5 | medium |
| ENV-03 | Thermal vacuum and thermal cycling with heaters, eclipse profile and survival mode; correlate the thermal model | THM-1, THM-2, LONG-1, PWR-2 | T | 20 | high |
| ENV-04 | EMC and RF: emissions, susceptibility, antenna patterns and link test in an anechoic setting; frequency compliance | COM-2, REG-1 | T | 10 | medium |
| ENV-05 | Battery safety tests required by the launch provider (vent, short, overcharge protection) and outgassing/bake-out | PWR-3, SYS-1 | T | 10 | medium |

### Precursor

| ID | Activity | Covers | Method | Days | External |
|---|---|---|---|---|---|
| PRE-01 | High-altitude balloon flight (about 30 km): Jetson, CM5, cameras, LoRa link, GNSS, magnetometer, dosimeter and the packet/ground chain | COM-2, COM-3, LONG-2 | D | 60 | medium |

### Ground

| ID | Activity | Covers | Method | Days | External |
|---|---|---|---|---|---|
| GND-01 | End-to-end ground chain: station at the reference site tracks a real satellite of opportunity, decodes and uploads to the archive; unattended operation for two weeks | COM-1, COM-2, OPEN-1, OPEN-2, OPEN-7, COLAV-4 | D | 30 | none |
| GND-02 | Open relay and protocol review: fuzz and interoperability test of the public message set with an independent decoder, quota and abuse drills, verification that no downlink content is obscured | OPEN-3, OPEN-4, OPEN-5, OPEN-6 | T | 15 | none |

### Review

| ID | Activity | Covers | Method | Days | External |
|---|---|---|---|---|---|
| REV-01 | Design reviews: preliminary and critical design review, safety review with the launch provider, licensing and coordination review | SYS-1, REG-1, COLAV-1, ORB-1, OPEN-1, LONG-4, COLAV-5, COLAV-6 | I | 40 | low |
| REV-02 | Operations readiness review: procedures, contact plan, collision-avoidance drill with a conjunction message, anomaly drills | COLAV-1, COLAV-2, COM-4, SIM-1 | D | 20 | none |

## Requirement coverage

| Requirement | Planned tests | Note |
|---|---|---|
| SYS-1 | ENV-01, ENV-05, REV-01 |  |
| SYS-2 | SYS-04 |  |
| SYS-3 | BRD-01, SYS-01 |  |
| SYS-4 | SYS-04 |  |
| SYS-5 | CMP-02, SUB-07, ENV-01 |  |
| STR-1 | CMP-02, SUB-07, ENV-01, ENV-02 |  |
| PWR-1 | BRD-02, SYS-01 |  |
| PWR-2 | CMP-01, SYS-01, ENV-03 |  |
| PWR-3 | CMP-01, BRD-02, BRD-03, SYS-03, ENV-05 |  |
| PWR-4 | CMP-02, BRD-02 |  |
| PWR-5 | CMP-02, SUB-07 |  |
| THM-1 | SUB-05, ENV-03 |  |
| THM-2 | SUB-06, ENV-03 |  |
| ADCS-1 | SUB-04 |  |
| ADCS-2 | SUB-04, SUB-05, SYS-04, SYS-05 |  |
| PROP-1 | SUB-05 |  |
| PROP-2 | SUB-05 |  |
| ORB-1 | REV-01 |  |
| COM-1 | GND-01 |  |
| COM-2 | ENV-04, PRE-01, GND-01 |  |
| COM-3 | SUB-02, SYS-01, PRE-01 |  |
| COM-4 | SUB-01, REV-02 |  |
| FW-1 | SYS-02 | waived: unit tests already run automatically on every check; hardware runs are covered by SYS-02 |
| DATA-1 | SUB-02, SUB-03 |  |
| LONG-1 | CMP-03, BRD-03, ENV-03 |  |
| LONG-2 | CMP-03, SYS-03, PRE-01 |  |
| LONG-3 | CMP-01, CMP-03 |  |
| SIM-1 | SYS-02, REV-02 | waived: software simulation result; the hardware-in-the-loop test HW-01 repeats it on real timing |
| FMEA-1 | SYS-03 | waived: document quality gate; its fault-injection consequences are covered by SYS-03 and SYS-05 |
| ELEC-1 | BRD-01, BRD-03 |  |
| ELEC-2 | BRD-01 |  |
| ELEC-3 | BRD-02 |  |
| OPEN-1 | GND-01, REV-01 |  |
| COLAV-1 | REV-01, REV-02 |  |
| REG-1 | ENV-04, REV-01 |  |
| COLAV-2 | REV-02 |  |
| COLAV-3 | SYS-09 |  |
| COLAV-4 | GND-01 |  |
| COLAV-5 | REV-01 |  |
| COLAV-6 | REV-01 |  |
| LONG-4 | REV-01 |  |
| OPEN-2 | GND-01 |  |
| OPEN-3 | GND-02 |  |
| OPEN-4 | GND-02 |  |
| OPEN-5 | GND-02 |  |
| OPEN-6 | GND-02 |  |
| OPEN-7 | GND-01 |  |

## Facilities and external cost drivers

- No external facility: 335 engineer-days (FlatSat, board work, software, ground).
- Low: 130 days; medium: 230 days; high: 85 days (radiation screening, thermal vacuum, thruster tests are the cost drivers).

## Open items

- Choose facilities and quotes; align test levels with the launch provider's requirements; decide flight-model versus proto-flight approach (one flight model reduces cost, raises risk).
- Write detailed procedures per test with pass/fail criteria linked to the requirement text; keep the results in the repository next to the requirement that they verify.

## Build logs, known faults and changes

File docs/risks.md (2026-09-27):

# Risk register (draft v0)

Likelihood (L) and impact (I) on a 1-5 scale; score = L x I. Mitigations are actions we can take before hardware exists. Reviewed by hand; extend as analyses mature.

| # | Risk | L | I | Score | Mitigation / next action |
|---|---|---|---|---|---|
| R1 | **No launch opportunity or sponsor** (12U rideshare, orbit >= 700 km, cost) | 4 | 5 | 20 | Tiered variants (`configs/`), sponsor brief, use the design as a reusable platform even without a flight; approach agencies and rideshare providers early |
| R2 | **Operator of record, frequency coordination and licensing** not in place (amateur bands, IARU, national authority) | 4 | 5 | 20 | Find a licensed operator/organisation partner; start coordination once the design is frozen (REG-1, COLAV-1); entry points identified (TRAC, BTK, IARU Satellite Adviser, `docs/ground-station-kit.md`), not yet started |
| R3 | **Single-person project scope** (5 processors, 26 instruments, firmware, ground) | 5 | 4 | 20 | Freeze a core mission; make research-level payloads optional; open the repository so others can own subsystems |
| R4 | **Cost** far beyond a hobby budget (cells, thruster, optics, tests) | 5 | 4 | 20 | Cost model per tier; sponsor packages; reuse commercial parts; start with a FlatSat and a balloon flight |
| R5 | **Double-sided thin wing panels (2.1 mm)** may not meet stiffness, mass or cost (PWR-5) | 3 | 4 | 12 | Prototype a panel; alternatives: wings on one side of the body only with reduced power, or 2 panels per wing with a recessed wall |
| R6 | **Residual magnetic dipole > 0.1 A m2** compromises the magnetometer and control | 4 | 3 | 12 | Magnetic cleanliness programme, material screening, dipole compensation, boom; measure on an engineering model |
| R7 | **Iodine thruster** power, thrust, plume or corrosion differ from the estimate (contamination of optics, cells, radiators) | 3 | 4 | 12 | Vendor data and plume map, contamination shielding, place thruster away from optics; keep the drag sail as passive backup |
| R8 | **Telescope pointing stability** (structural modes, wheel micro-vibration) worse than the rigid-body estimate | 3 | 4 | 12 | Modal analysis, isolators, jitter test on an engineering model; relax GSD or use TDI |
| R9 | **COTS compute (Jetson, Pi) dies early** from radiation or latch-up | 4 | 2 | 8 | Already tiered: science chain does not depend on Linux nodes (LONG-2); radiation vault for the control electronics; treat as consumables |
| R10 | **Volume estimates wrong** (bounding boxes, +-30 %) | 3 | 3 | 9 | Replace with vendor CAD as parts are chosen; about 36 % of the interior is free by voxel packing but fragmented |
| R11 | **Thermal model wrong** (coatings, conduction estimated) | 3 | 3 | 9 | Detailed nodal model, thermal-vacuum test; heaters give margin; dawn-dusk orbit preferred |
| R12 | **Thermal cycling fatigue** of solder joints (5000+ cycles/yr in eclipse orbits) | 3 | 3 | 9 | Design rules (CTE match, underfill, conformal coating), test; dawn-dusk orbit reduces cycling |
| R13 | **Volunteer S-band ground network too thin**; only the home station at Pamukkale (3.7 passes/day) | 3 | 3 | 9 | Ground kit design, at least two anchor stations (COLAV-4; second-site proposal in `docs/ground-station-kit.md`, not yet arranged), UHF beacon as fallback |
| R14 | **Collision avoidance response time** (few passes/day, commands 24-48 h ahead) | 3 | 4 | 12 | Second station for commanding, autonomous burn execution, keep orbit >= 700 km where conjunctions are rarer |
| R15 | **Ed25519 signing and OTA not implemented**; security model not reviewed | 3 | 4 | 12 | Vetted library, tests, security review before any flight software release (COM-4) |
| R16 | **Debris or micrometeoroid strike** (1 mm - 1 cm class cannot be shielded or tracked) | 2 | 5 | 10 | Redundancy (A/B/C power, computer hierarchy, survival chain), Whipple protection on tank and batteries |
| R17 | **Battery ageing** faster than modelled (LiFePO4 at 5000 cycles/yr) | 3 | 3 | 9 | Larger pack (done), sun-only mode, survival pack; test cells for the LEO cycling profile |
| R18 | **Deployment failure** of wings or antenna | 2 | 4 | 8 | Body cells alone keep safe mode alive (10.9 W vs 3.1 W); independent burn-wire supply on the survival bus |
| R19 | **Parts sourcing and export controls** (iodine thruster, triple-junction cells, Jetson) | 3 | 3 | 9 | Identify alternatives per part; check regulations early; keep interfaces vendor-neutral |
| R20 | **Requirements drift** between design documents | 3 | 2 | 6 | Verification matrix (`sim/trace_check.py`) and configs as the single source keep documents consistent |
| R21 | **Name and trademark** ("Wollemi") conflicts | 2 | 2 | 4 | Check trademarks before going public; the name is easy to change |
| R22 | **Prior-art or patent conflict** with card/backplane concepts | 2 | 3 | 6 | Prior-art review done (`docs/prior-art.md`), full search before publication; credit OreSat |

## Top actions right now

1. R1/R2/R3/R4: decide the real target: a flight mission, a flight-quality reference design, or a balloon/FlatSat first step (this decides the effort).
2. R5: prototype a double-sided panel and confirm the power model assumption.
3. R6: define a magnetic cleanliness plan before choosing parts.
4. R15: implement signature verification and tests.
5. R7/R8: obtain vendor data (thruster plume, optics tube modes).

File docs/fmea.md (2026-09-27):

# FMEA (generated)

Source: `mission/fmea.toml`; generated and checked by `python tools/fmea_check.py`. Severity S, likelihood L, detection difficulty D on 1-5; RPN = S x L x D.

42 failure modes over 10 subsystems; 19 with severity >= 4 (all have a detection and a response).

## Highest risk priority numbers

| RPN | ID | Item | Failure mode | S | L | D | Response (FDIR class) |
|---|---|---|---|---|---|---|---|
| 36 | PRP-03 | Iodine plume and corrosion | contamination of optics, cells or radiators | 3 | 3 | 4 | thruster placed away from optics and cells with canted exhaust; limit burn hours; plume shielding (`design`) |
| 36 | SWD-02 | Flight software defect | logic error in FDIR or mode manager | 4 | 3 | 3 | supervisor independent of flight software; safe mode; patch via OTA (`survival_mode`) |
| 36 | GND-02 | Loss of operator or organisation over decades | no one commands or receives | 3 | 4 | 3 | open protocol and tools, public archive, autonomy in the survival chain; documented operator hand-over (`design`) |
| 30 | COM-02 | UHF radio and antenna | antenna fails to deploy or radio fails | 5 | 2 | 3 | survival beacon designed as a separate low-power path; deployment retried with burn-wire on the survival supply (`retry`) |
| 27 | PWR-07 | Survival chain (pack C, survival string) | pack C dead or string open | 3 | 3 | 3 | supervisor keeps running from bus A/B; beacon designed to run direct from the solar string (sun-only) (`design`) |
| 24 | PWR-05 | Both main packs | both packs fail or fade below eclipse needs | 4 | 3 | 2 | sun-only mode (heavy loads only in sunlight), survival bus keeps supervisor and beacon (`sun_only`) |
| 24 | THM-04 | Multilayer insulation / coating degradation | gradual optical property change (UV, atomic oxygen, contamination) | 2 | 4 | 3 | heater and duty-cycle adjustment from the ground; wider margins (`ground_action`) |
| 24 | CMP-05 | Mass memory unit | one or two flash devices fail; controller hang | 3 | 4 | 2 | 6+2 erasure coding, adaptive stripe width; controller restart; data downlinked and released as soon as acknowledged (`restart`) |
| 24 | PRP-01 | Electric thruster | fails to start or loses thrust | 4 | 3 | 2 | abort burn, drag sail as passive disposal, planning without manoeuvres (`degrade`) |
| 24 | STR-02 | Launch damage (vibration, shock) | loosened fastener, cracked solder, panel damage | 4 | 2 | 3 | design margins (docs/structure.md), workmanship, environmental tests, staged commissioning (`design`) |
| 24 | SWD-03 | Key or signature failure | operational key lost or compromised | 4 | 2 | 3 | previous key still valid, key_rotate signed by the offline root key (`ground_action`) |
| 24 | GND-01 | Operator error | wrong command or wrong sequence uploaded | 4 | 3 | 2 | time-tagged sequences validated against power/attitude/thermal state on the ground; expiry windows; two-person rule for manoeuvres (`ground_action`) |
| 20 | PWR-04 | Battery pack A or B | cell short, open cell, overheating | 5 | 2 | 2 | hardware disconnect and fuse; vault contains the event; operate on the other pack and the survival pack (`hardware`) |
| 20 | PWR-08 | Charge control | charger fails to stop (overcharge) or charges below 0 C | 5 | 2 | 2 | hardware OVP/UVP and low-temperature charge inhibit (`hardware`) |
| 18 | THM-03 | Propulsion bay and tank | iodine tank overheats or freezes plumbing / cold spots | 3 | 3 | 2 | burn aborted, bay isolated, heaters thermostatic; mode manager leaves BURN (`degrade`) |

## All failure modes by subsystem

### ADCS

| ID | Item | Failure mode | Effect | Detection | Response | FDIR | S | L | D |
|---|---|---|---|---|---|---|---|---|---|
| ADC-01 | Reaction wheel | wheel failure or bearing wear | one axis lost; slews and pointing degraded | wheel speed and current telemetry, pointing error | remaining wheels plus magnetorquers; degraded imaging; safe mode sun-pointing by torquers | `degrade` | 3 | 3 | 2 |
| ADC-02 | Magnetorquer or driver | stuck on | uncontrolled torque, magnetic disturbance to the magnetometer | torquer current telemetry, attitude drift | hardware current limit, driver disabled by supervisor, wheels take over | `kill` | 3 | 2 | 2 |
| ADC-03 | Star tracker | blinded by the Sun or Earth, or failed | no fine attitude | solution quality flags | gyro/sun-sensor propagation, coarse pointing mode, tracker exclusion angles from the wing geometry | `degrade` | 3 | 3 | 2 |
| ADC-04 | Attitude loss after separation or fault | tumbling | power falls to 28 W average with wings, 11 W on body cells; no burns or imaging | rate gyros, sun sensors | detumble with magnetorquers in safe mode; body-cell power covers the safe loads | `safe_mode` | 3 | 3 | 1 |

### Comms

| ID | Item | Failure mode | Effect | Detection | Response | FDIR | S | L | D |
|---|---|---|---|---|---|---|---|---|---|
| COM-01 | S-band transmitter | power amplifier failure | no bulk downlink; UHF only (about 0.5 MB/day) | TX telemetry, ground non-reception | UHF carries priority-1 subsets; ground commands the spare or repeats | `degrade` | 3 | 3 | 2 |
| COM-02 | UHF radio and antenna | antenna fails to deploy or radio fails | loss of beacon and commanding path | no contact at expected passes | survival beacon designed as a separate low-power path; deployment retried with burn-wire on the survival supply | `retry` | 5 | 2 | 3 |
| COM-03 | Command channel | replay or forged telecommand | unauthorised spacecraft control | signature, counter and validity check (wl_auth) | command rejected and logged; key rotation available | `design` | 5 | 2 | 1 |
| COM-04 | Ground network | single station outage (weather, failure, power) | no contacts for a day or more; collision-avoidance commands delayed | planned contact log | second station, volunteer network, autonomous store-and-forward; commanding planned with 24-48 h margin | `ground_action` | 3 | 4 | 1 |

### Compute

| ID | Item | Failure mode | Effect | Detection | Response | FDIR | S | L | D |
|---|---|---|---|---|---|---|---|---|---|
| CMP-01 | Flight controller | hang or single-event upset | loss of control functions | supervisor watchdog and CAN heartbeat | escalation retry, restart, power-cycle, switch to FC-B; SURVIVAL mode if all fail | `power_cycle` | 4 | 3 | 1 |
| CMP-02 | Radiation latch-up on any card | current runaway in a COTS device | card overheats, bus sag | eFuse over-current trip | eFuse latches off, retry after a delay; permanent latch-up leaves the card off | `hardware` | 3 | 4 | 1 |
| CMP-03 | Jetson Orin Nano | death by radiation or fault | no heavy processing (imaging pipeline degraded) | heartbeat and error counters | degradation level 1; SCIENCE_LITE on the CM5; science chain unaffected | `degrade` | 2 | 4 | 1 |
| CMP-04 | Pi CM5 | death | no bulk data handling or S-band engine on the Linux side | heartbeat | FC and MMU keep the long-life science chain and downlink via the S-band modem interface | `degrade` | 3 | 4 | 1 |
| CMP-05 | Mass memory unit | one or two flash devices fail; controller hang | capacity loss; risk of data loss on a third failure | scrubbing errors, device status (mmu_status) | 6+2 erasure coding, adaptive stripe width; controller restart; data downlinked and released as soon as acknowledged | `restart` | 3 | 4 | 2 |
| CMP-06 | Time base | loss of GNSS/CSAC lock or clock drift | timestamps degraded, time-tagged commands mis-timed | clock quality bits, PPS monitoring | fall back to the FC oscillator with quality flag; ground time_set command | `degrade` | 3 | 3 | 2 |
| CMP-07 | Supervisor (MSP430FR) | hang or upset | no watchdog and no beacon | its own hardware watchdog; external supervisor timer | hardware watchdog reset; FRAM state protected by checksums; stays the simplest and best-shielded device | `hardware` | 5 | 1 | 2 |

### Ground

| ID | Item | Failure mode | Effect | Detection | Response | FDIR | S | L | D |
|---|---|---|---|---|---|---|---|---|---|
| GND-01 | Operator error | wrong command or wrong sequence uploaded | unintended mode, burn or data deletion | ground checks, validity windows, simulation before upload | time-tagged sequences validated against power/attitude/thermal state on the ground; expiry windows; two-person rule for manoeuvres | `ground_action` | 4 | 3 | 2 |
| GND-02 | Loss of operator or organisation over decades | no one commands or receives | open-loop spacecraft; data unrecovered | project governance review | open protocol and tools, public archive, autonomy in the survival chain; documented operator hand-over | `design` | 3 | 4 | 3 |

### Payload

| ID | Item | Failure mode | Effect | Detection | Response | FDIR | S | L | D |
|---|---|---|---|---|---|---|---|---|---|
| PAY-01 | Telescope and hyperspectral optics | contamination, defocus, mechanical shift | image quality loss | calibration targets, star fields, focus telemetry | calibration campaigns, thermal control, focus adjustment from the ground | `ground_action` | 2 | 3 | 3 |
| PAY-02 | Long-life science chain sensors | individual instrument failure (magnetometer, TSI, dosimeter...) | loss of that data record | instrument health flags and data validity | other instruments continue; redundant dosimetry; ground reconfiguration | `degrade` | 2 | 3 | 2 |
| PAY-03 | Outreach LED flasher | stuck on or unintended flash during imaging | stray light, power drain, sky nuisance | LED current telemetry | hardware maximum on-time and thermal cut-off; disabled by mode manager in SCIENCE and SAFE | `hardware` | 2 | 2 | 2 |

### Power

| ID | Item | Failure mode | Effect | Detection | Response | FDIR | S | L | D |
|---|---|---|---|---|---|---|---|---|---|
| PWR-01 | Solar wing string (one panel) | open circuit or short of a panel string | loss of about 1/6 of wing power; MPPT channel idles | per-channel current and voltage telemetry (hk_power), string current comparison | MPPT channel disabled, other channels continue; ground informed | `degrade` | 2 | 3 | 2 |
| PWR-02 | Wing deployment | wing fails to deploy or one panel jams | generation limited to body cells (10.9 W tumbling); imaging and burns impossible | deployment confirmation switches, generation vs sun angle | retry burn wire (independent survival supply), then safe mode on body cells; ground decides on operations without wings | `retry` | 4 | 2 | 2 |
| PWR-03 | MPPT / EPS-A card | card failure (short, no output) | wing A power lost, pack A charger lost; bus B and pack B continue | loss of EPS-A telemetry, bus A voltage, heartbeat | isolated by ideal diode; supervisor kills the slot if needed; operate on EPS-B and half the power | `switch_redundant` | 3 | 2 | 2 |
| PWR-04 | Battery pack A or B | cell short, open cell, overheating | one pack lost; risk of venting or fire in the vault | pack voltage/current/temperature, BMS flags, hardware cut-off | hardware disconnect and fuse; vault contains the event; operate on the other pack and the survival pack | `hardware` | 5 | 2 | 2 |
| PWR-05 | Both main packs | both packs fail or fade below eclipse needs | no eclipse operation; sun-only mode | state-of-charge model, eclipse voltage sag | sun-only mode (heavy loads only in sunlight), survival bus keeps supervisor and beacon | `sun_only` | 4 | 3 | 2 |
| PWR-06 | Bus short circuit or card short | short on a card input or backplane | voltage collapse on one bus | per-card eFuse trip, FAULT_N wired-OR, bus voltage monitor | the card's own eFuse latches off; supervisor kills the slot with SLOT_SEL/KILL_N if it stays faulty | `kill` | 4 | 2 | 2 |
| PWR-07 | Survival chain (pack C, survival string) | pack C dead or string open | supervisor and beacon rely on the main buses only | pack C telemetry; loss of survival-path current | supervisor keeps running from bus A/B; beacon designed to run direct from the solar string (sun-only) | `design` | 3 | 3 | 3 |
| PWR-08 | Charge control | charger fails to stop (overcharge) or charges below 0 C | cell damage, plating, vent risk | cell voltage and temperature comparators independent of software | hardware OVP/UVP and low-temperature charge inhibit | `hardware` | 5 | 2 | 2 |

### Propulsion

| ID | Item | Failure mode | Effect | Detection | Response | FDIR | S | L | D |
|---|---|---|---|---|---|---|---|---|---|
| PRP-01 | Electric thruster | fails to start or loses thrust | no station keeping or collision avoidance; no controlled descent | thruster telemetry, no delta-v measured from GNSS | abort burn, drag sail as passive disposal, planning without manoeuvres | `degrade` | 4 | 3 | 2 |
| PRP-02 | Thruster stuck on / valve or heater failure | uncommanded thrust | orbit change and torque, propellant loss | acceleration from GNSS/gyros, thruster telemetry | hardware cut through the supervisor kill path and the three-inhibit chain; power removed | `kill` | 4 | 1 | 2 |
| PRP-03 | Iodine plume and corrosion | contamination of optics, cells or radiators | gradual loss of optical performance and power | image degradation, generation trend | thruster placed away from optics and cells with canted exhaust; limit burn hours; plume shielding | `design` | 3 | 3 | 4 |
| PRP-04 | Thrust line off the centre of mass | CoM shift beyond +-5 mm (ballast, propellant use) | torque during burns exceeds the magnetorquer capacity; wheel saturation | wheel momentum during burns | shorter burns with dumping; ground updates the cant/CoM model; burn aborted on saturation | `safe_mode` | 3 | 3 | 2 |

### Software

| ID | Item | Failure mode | Effect | Detection | Response | FDIR | S | L | D |
|---|---|---|---|---|---|---|---|---|---|
| SWD-01 | Over-the-air update | corrupt or interrupted update | node fails to boot the new image | hash check before commit, confirm timeout | A/B slots, confirm-or-rollback (wl_ota); never overwrite the running slot | `design` | 4 | 3 | 1 |
| SWD-02 | Flight software defect | logic error in FDIR or mode manager | wrong mode or missed recovery | unit tests, closed-loop simulation, hardware-in-the-loop, telemetry review | supervisor independent of flight software; safe mode; patch via OTA | `survival_mode` | 4 | 3 | 3 |
| SWD-03 | Key or signature failure | operational key lost or compromised | cannot command, or unauthorised command risk | rejected commands, ground audit | previous key still valid, key_rotate signed by the offline root key | `ground_action` | 4 | 2 | 3 |

### Structure

| ID | Item | Failure mode | Effect | Detection | Response | FDIR | S | L | D |
|---|---|---|---|---|---|---|---|---|---|
| STR-01 | Burn-wire / hold-down release | release does not occur | wing or antenna stays stowed | deployment switches | retry, second wire, independent supply; see PWR-02 and COM-02 | `retry` | 4 | 2 | 2 |
| STR-02 | Launch damage (vibration, shock) | loosened fastener, cracked solder, panel damage | any function may fail at first contact | post-launch checkout of every subsystem | design margins (docs/structure.md), workmanship, environmental tests, staged commissioning | `design` | 4 | 2 | 3 |
| STR-03 | Debris or micrometeoroid impact | penetration of tank, vault or electronics; solar panel damage | random failures up to loss of mission | impact sensor, sudden telemetry change | Whipple protection on tank and batteries, redundancy (A/B/C), collision avoidance for tracked objects | `design` | 5 | 1 | 3 |

### Thermal

| ID | Item | Failure mode | Effect | Detection | Response | FDIR | S | L | D |
|---|---|---|---|---|---|---|---|---|---|
| THM-01 | Battery heater or thermostat | stuck off or stuck on | cold battery (no charging) or overheating | vault temperature, heater current telemetry | hardware over-temperature cut-off; charge inhibit below 0 C; second heater element | `hardware` | 4 | 2 | 2 |
| THM-02 | Telescope column heater | fails off in eclipse orbits | optics cold, swing beyond 6 K; imaging degraded, possible focus shift | column temperature sensors | imaging inhibited outside the temperature window; ground reconfigures the orbit plan | `degrade` | 2 | 3 | 2 |
| THM-03 | Propulsion bay and tank | iodine tank overheats or freezes plumbing / cold spots | thruster cannot start or wrong pressure; heat into neighbours | tank and bay temperature sensors, thruster telemetry | burn aborted, bay isolated, heaters thermostatic; mode manager leaves BURN | `degrade` | 3 | 3 | 2 |
| THM-04 | Multilayer insulation / coating degradation | gradual optical property change (UV, atomic oxygen, contamination) | temperatures drift over the years | long-term temperature trend vs the model | heater and duty-cycle adjustment from the ground; wider margins | `ground_action` | 2 | 4 | 3 |

## Limits

Qualitative and estimated by the design team, not derived from part-level failure-rate data. It should be reviewed independently, extended to part level (each card and connector), and turned into a fault-injection test list (`docs/test-plan.md`).

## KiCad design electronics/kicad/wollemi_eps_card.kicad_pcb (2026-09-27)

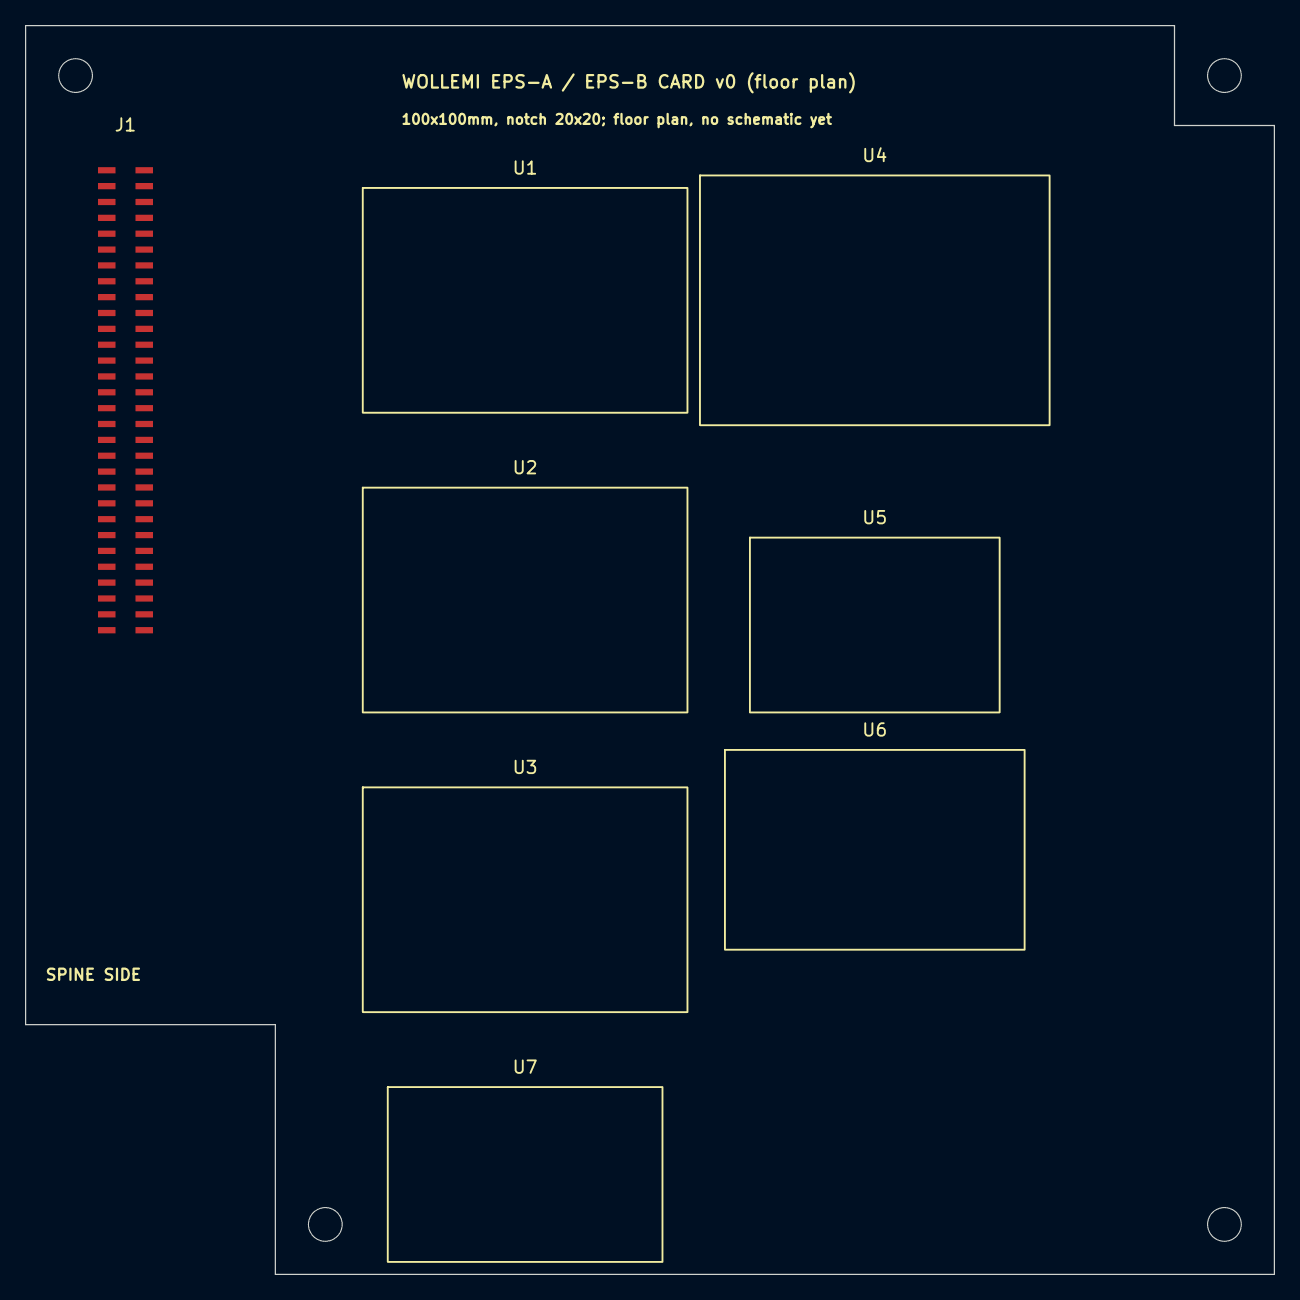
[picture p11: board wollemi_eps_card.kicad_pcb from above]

Board: 4 copper layers, 100.0 x 100.0 mm, 12 parts (0 on the bottom side), 4 nets, no tracks yet.

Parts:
H: M2.5; MountingHole_2.7mm_M2.5
H#2, H#3, H#4: M2.5; MountingHole_2.7mm_M2.5
J1: WL-P; WL-P_placeholder
U1, U2, U3: LT8490; LT8490_placeholder
U4: BQ29209-Q1; BQ29209-Q1_placeholder
U5: LTC4359; LTC4359_placeholder
U6: TPS2597x; TPS2597x_placeholder
U7: STM32G0B1; STM32G0B1_placeholder

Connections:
GND: J1.11, J1.12, J1.15, J1.16, J1.19, J1.20, J1.23, J1.24, J1.27, J1.28, J1.39, J1.40, J1.45, J1.46, J1.51, J1.52
RSV: J1.54, J1.55, J1.56, J1.57, J1.58, J1.59, J1.60
VBAT_A: J1.1, J1.3, J1.5, J1.7, J1.9
VBAT_B: J1.2, J1.4, J1.6, J1.8, J1.10

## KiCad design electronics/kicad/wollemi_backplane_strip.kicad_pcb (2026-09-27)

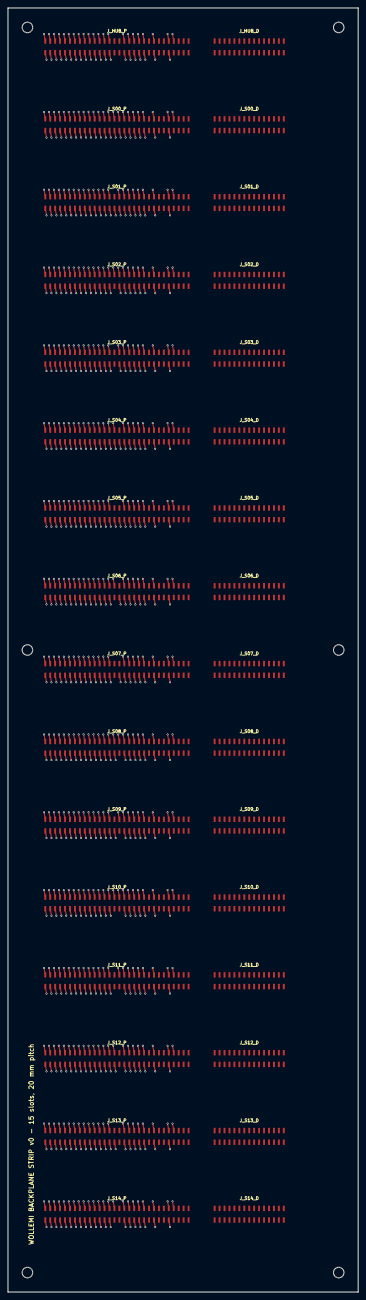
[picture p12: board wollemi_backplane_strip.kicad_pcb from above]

Board: 6 copper layers, 90.0 x 330.0 mm, 38 parts (0 on the bottom side), 20 nets.

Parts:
H: M2.5; MountingHole_2.7mm_M2.5
H#2, H#3, H#4, H#5, H#6: M2.5; MountingHole_2.7mm_M2.5
J_HUB_D: WL-D; WL-D_backplane_placeholder
J_HUB_P: WL-P; WL-P_backplane_placeholder
J_S00_D, J_S01_D, J_S02_D, J_S03_D, J_S04_D, J_S05_D, J_S06_D, J_S07_D, J_S08_D, J_S09_D, J_S10_D, J_S11_D, J_S12_D, J_S13_D, J_S14_D: WL-D; WL-D_backplane_placeholder
J_S00_P, J_S01_P, J_S02_P, J_S03_P, J_S04_P, J_S05_P, J_S06_P, J_S07_P, J_S08_P, J_S09_P, J_S10_P, J_S11_P, J_S12_P, J_S13_P, J_S14_P: WL-P; WL-P_backplane_placeholder

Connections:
CAN_A_H: J_HUB_P.13, J_S00_P.13, J_S01_P.13, J_S02_P.13, J_S03_P.13, J_S04_P.13, J_S05_P.13, J_S06_P.13, J_S07_P.13, J_S08_P.13, J_S09_P.13, J_S10_P.13, J_S11_P.13, J_S12_P.13, J_S13_P.13, J_S14_P.13
CAN_A_L: J_HUB_P.14, J_S00_P.14, J_S01_P.14, J_S02_P.14, J_S03_P.14, J_S04_P.14, J_S05_P.14, J_S06_P.14, J_S07_P.14, J_S08_P.14, J_S09_P.14, J_S10_P.14, J_S11_P.14, J_S12_P.14, J_S13_P.14, J_S14_P.14
CAN_B_H: J_HUB_P.17, J_S00_P.17, J_S01_P.17, J_S02_P.17, J_S03_P.17, J_S04_P.17, J_S05_P.17, J_S06_P.17, J_S07_P.17, J_S08_P.17, J_S09_P.17, J_S10_P.17, J_S11_P.17, J_S12_P.17, J_S13_P.17, J_S14_P.17
CAN_B_L: J_HUB_P.18, J_S00_P.18, J_S01_P.18, J_S02_P.18, J_S03_P.18, J_S04_P.18, J_S05_P.18, J_S06_P.18, J_S07_P.18, J_S08_P.18, J_S09_P.18, J_S10_P.18, J_S11_P.18, J_S12_P.18, J_S13_P.18, J_S14_P.18
FAULT_N: J_HUB_P.38, J_S00_P.38, J_S01_P.38, J_S02_P.38, J_S03_P.38, J_S04_P.38, J_S05_P.38, J_S06_P.38, J_S07_P.38, J_S08_P.38, J_S09_P.38, J_S10_P.38, J_S11_P.38, J_S12_P.38, J_S13_P.38, J_S14_P.38
GND: J_HUB_P.11, J_HUB_P.12, J_HUB_P.15, J_HUB_P.16, J_HUB_P.19, J_HUB_P.20, J_HUB_P.23, J_HUB_P.24, J_HUB_P.27, J_HUB_P.28, J_HUB_P.39, J_HUB_P.40, J_HUB_P.45, J_HUB_P.46, J_HUB_P.51, J_HUB_P.52, J_S00_P.11, J_S00_P.12, J_S00_P.15, J_S00_P.16, J_S00_P.19, J_S00_P.20, J_S00_P.23, J_S00_P.24, J_S00_P.27, J_S00_P.28, J_S00_P.29, J_S00_P.30, J_S00_P.31, J_S00_P.32, J_S00_P.39, J_S00_P.40, J_S00_P.45, J_S00_P.46, J_S00_P.51, J_S00_P.52, J_S01_P.11, J_S01_P.12, J_S01_P.15, J_S01_P.16, J_S01_P.19, J_S01_P.20, J_S01_P.23, J_S01_P.24, J_S01_P.27, J_S01_P.28, J_S01_P.30, J_S01_P.31, J_S01_P.32, J_S01_P.39, J_S01_P.40, J_S01_P.45, J_S01_P.46, J_S01_P.51, J_S01_P.52, J_S02_P.11, J_S02_P.12, J_S02_P.15, J_S02_P.16, J_S02_P.19, J_S02_P.20, J_S02_P.23, J_S02_P.24, J_S02_P.27, J_S02_P.28, J_S02_P.29, J_S02_P.31, J_S02_P.32, J_S02_P.39, J_S02_P.40, J_S02_P.45, J_S02_P.46, J_S02_P.51, J_S02_P.52, J_S03_P.11, J_S03_P.12, J_S03_P.15, J_S03_P.16, J_S03_P.19, J_S03_P.20, J_S03_P.23, J_S03_P.24, J_S03_P.27, J_S03_P.28, J_S03_P.31, J_S03_P.32, J_S03_P.39, J_S03_P.40, J_S03_P.45, J_S03_P.46, J_S03_P.51, J_S03_P.52, J_S04_P.11, J_S04_P.12, J_S04_P.15, J_S04_P.16, J_S04_P.19, J_S04_P.20, J_S04_P.23, J_S04_P.24, J_S04_P.27, J_S04_P.28, J_S04_P.29, J_S04_P.30, J_S04_P.32, J_S04_P.39, J_S04_P.40, J_S04_P.45, J_S04_P.46, J_S04_P.51, J_S04_P.52, J_S05_P.11, J_S05_P.12, J_S05_P.15, J_S05_P.16, J_S05_P.19, J_S05_P.20, J_S05_P.23, J_S05_P.24, J_S05_P.27, J_S05_P.28, J_S05_P.30, J_S05_P.32, J_S05_P.39, J_S05_P.40, J_S05_P.45, J_S05_P.46, J_S05_P.51, J_S05_P.52, J_S06_P.11, J_S06_P.12, J_S06_P.15, J_S06_P.16, J_S06_P.19, J_S06_P.20, J_S06_P.23, J_S06_P.24, J_S06_P.27, J_S06_P.28, J_S06_P.29, J_S06_P.32, J_S06_P.39, J_S06_P.40, J_S06_P.45, J_S06_P.46, J_S06_P.51, J_S06_P.52, J_S07_P.11, J_S07_P.12, J_S07_P.15, J_S07_P.16, J_S07_P.19, J_S07_P.20, J_S07_P.23, J_S07_P.24, J_S07_P.27, J_S07_P.28, J_S07_P.32, J_S07_P.39, J_S07_P.40, J_S07_P.45, J_S07_P.46, J_S07_P.51, J_S07_P.52, J_S08_P.11, J_S08_P.12, J_S08_P.15, J_S08_P.16, J_S08_P.19, J_S08_P.20, J_S08_P.23, J_S08_P.24, J_S08_P.27, J_S08_P.28, J_S08_P.29, J_S08_P.30, J_S08_P.31, J_S08_P.39, J_S08_P.40, J_S08_P.45, J_S08_P.46, J_S08_P.51, J_S08_P.52, J_S09_P.11, J_S09_P.12, J_S09_P.15, J_S09_P.16, J_S09_P.19, J_S09_P.20, J_S09_P.23, J_S09_P.24, J_S09_P.27, J_S09_P.28, J_S09_P.30, J_S09_P.31, J_S09_P.39, J_S09_P.40, J_S09_P.45, J_S09_P.46, J_S09_P.51, J_S09_P.52, J_S10_P.11, J_S10_P.12, J_S10_P.15, J_S10_P.16, J_S10_P.19, J_S10_P.20, J_S10_P.23, J_S10_P.24, J_S10_P.27, J_S10_P.28, J_S10_P.29, J_S10_P.31, J_S10_P.39, J_S10_P.40, J_S10_P.45, J_S10_P.46, J_S10_P.51, J_S10_P.52, J_S11_P.11, J_S11_P.12, J_S11_P.15, J_S11_P.16, J_S11_P.19, J_S11_P.20, J_S11_P.23, J_S11_P.24, J_S11_P.27, J_S11_P.28, J_S11_P.31, J_S11_P.39, J_S11_P.40, J_S11_P.45, J_S11_P.46, J_S11_P.51, J_S11_P.52, J_S12_P.11, J_S12_P.12, J_S12_P.15, J_S12_P.16, J_S12_P.19, J_S12_P.20, J_S12_P.23, J_S12_P.24, J_S12_P.27, J_S12_P.28, J_S12_P.29, J_S12_P.30, J_S12_P.39, J_S12_P.40, J_S12_P.45, J_S12_P.46, J_S12_P.51, J_S12_P.52, J_S13_P.11, J_S13_P.12, J_S13_P.15, J_S13_P.16, J_S13_P.19, J_S13_P.20, J_S13_P.23, J_S13_P.24, J_S13_P.27, J_S13_P.28, J_S13_P.30, J_S13_P.39, J_S13_P.40, J_S13_P.45, J_S13_P.46, J_S13_P.51, J_S13_P.52, J_S14_P.11, J_S14_P.12, J_S14_P.15, J_S14_P.16, J_S14_P.19, J_S14_P.20, J_S14_P.23, J_S14_P.24, J_S14_P.27, J_S14_P.28, J_S14_P.29, J_S14_P.39, J_S14_P.40, J_S14_P.45, J_S14_P.46, J_S14_P.51, J_S14_P.52
I2C_SCL: J_HUB_P.41, J_S00_P.41, J_S01_P.41, J_S02_P.41, J_S03_P.41, J_S04_P.41, J_S05_P.41, J_S06_P.41, J_S07_P.41, J_S08_P.41, J_S09_P.41, J_S10_P.41, J_S11_P.41, J_S12_P.41, J_S13_P.41, J_S14_P.41
I2C_SDA: J_HUB_P.42, J_S00_P.42, J_S01_P.42, J_S02_P.42, J_S03_P.42, J_S04_P.42, J_S05_P.42, J_S06_P.42, J_S07_P.42, J_S08_P.42, J_S09_P.42, J_S10_P.42, J_S11_P.42, J_S12_P.42, J_S13_P.42, J_S14_P.42
KILL_N: J_HUB_P.37, J_S00_P.37, J_S01_P.37, J_S02_P.37, J_S03_P.37, J_S04_P.37, J_S05_P.37, J_S06_P.37, J_S07_P.37, J_S08_P.37, J_S09_P.37, J_S10_P.37, J_S11_P.37, J_S12_P.37, J_S13_P.37, J_S14_P.37
PPS_N: J_HUB_P.22, J_S00_P.22, J_S01_P.22, J_S02_P.22, J_S03_P.22, J_S04_P.22, J_S05_P.22, J_S06_P.22, J_S07_P.22, J_S08_P.22, J_S09_P.22, J_S10_P.22, J_S11_P.22, J_S12_P.22, J_S13_P.22, J_S14_P.22
PPS_P: J_HUB_P.21, J_S00_P.21, J_S01_P.21, J_S02_P.21, J_S03_P.21, J_S04_P.21, J_S05_P.21, J_S06_P.21, J_S07_P.21, J_S08_P.21, J_S09_P.21, J_S10_P.21, J_S11_P.21, J_S12_P.21, J_S13_P.21, J_S14_P.21
RESET_N: J_HUB_P.53, J_S00_P.53, J_S01_P.53, J_S02_P.53, J_S03_P.53, J_S04_P.53, J_S05_P.53, J_S06_P.53, J_S07_P.53, J_S08_P.53, J_S09_P.53, J_S10_P.53, J_S11_P.53, J_S12_P.53, J_S13_P.53, J_S14_P.53
SLOT_SEL0: J_HUB_P.33, J_S00_P.33, J_S01_P.33, J_S02_P.33, J_S03_P.33, J_S04_P.33, J_S05_P.33, J_S06_P.33, J_S07_P.33, J_S08_P.33, J_S09_P.33, J_S10_P.33, J_S11_P.33, J_S12_P.33, J_S13_P.33, J_S14_P.33
SLOT_SEL1: J_HUB_P.34, J_S00_P.34, J_S01_P.34, J_S02_P.34, J_S03_P.34, J_S04_P.34, J_S05_P.34, J_S06_P.34, J_S07_P.34, J_S08_P.34, J_S09_P.34, J_S10_P.34, J_S11_P.34, J_S12_P.34, J_S13_P.34, J_S14_P.34
SLOT_SEL2: J_HUB_P.35, J_S00_P.35, J_S01_P.35, J_S02_P.35, J_S03_P.35, J_S04_P.35, J_S05_P.35, J_S06_P.35, J_S07_P.35, J_S08_P.35, J_S09_P.35, J_S10_P.35, J_S11_P.35, J_S12_P.35, J_S13_P.35, J_S14_P.35
SLOT_SEL3: J_HUB_P.36, J_S00_P.36, J_S01_P.36, J_S02_P.36, J_S03_P.36, J_S04_P.36, J_S05_P.36, J_S06_P.36, J_S07_P.36, J_S08_P.36, J_S09_P.36, J_S10_P.36, J_S11_P.36, J_S12_P.36, J_S13_P.36, J_S14_P.36
SYNC_N: J_HUB_P.26, J_S00_P.26, J_S01_P.26, J_S02_P.26, J_S03_P.26, J_S04_P.26, J_S05_P.26, J_S06_P.26, J_S07_P.26, J_S08_P.26, J_S09_P.26, J_S10_P.26, J_S11_P.26, J_S12_P.26, J_S13_P.26, J_S14_P.26
SYNC_P: J_HUB_P.25, J_S00_P.25, J_S01_P.25, J_S02_P.25, J_S03_P.25, J_S04_P.25, J_S05_P.25, J_S06_P.25, J_S07_P.25, J_S08_P.25, J_S09_P.25, J_S10_P.25, J_S11_P.25, J_S12_P.25, J_S13_P.25, J_S14_P.25
VBAT_A: J_HUB_P.1, J_HUB_P.3, J_HUB_P.5, J_HUB_P.7, J_HUB_P.9, J_S00_P.1, J_S00_P.3, J_S00_P.5, J_S00_P.7, J_S00_P.9, J_S01_P.1, J_S01_P.3, J_S01_P.5, J_S01_P.7, J_S01_P.9, J_S02_P.1, J_S02_P.3, J_S02_P.5, J_S02_P.7, J_S02_P.9, J_S03_P.1, J_S03_P.3, J_S03_P.5, J_S03_P.7, J_S03_P.9, J_S04_P.1, J_S04_P.3, J_S04_P.5, J_S04_P.7, J_S04_P.9, J_S05_P.1, J_S05_P.3, J_S05_P.5, J_S05_P.7, J_S05_P.9, J_S06_P.1, J_S06_P.3, J_S06_P.5, J_S06_P.7, J_S06_P.9, J_S07_P.1, J_S07_P.3, J_S07_P.5, J_S07_P.7, J_S07_P.9, J_S08_P.1, J_S08_P.3, J_S08_P.5, J_S08_P.7, J_S08_P.9, J_S09_P.1, J_S09_P.3, J_S09_P.5, J_S09_P.7, J_S09_P.9, J_S10_P.1, J_S10_P.3, J_S10_P.5, J_S10_P.7, J_S10_P.9, J_S11_P.1, J_S11_P.3, J_S11_P.5, J_S11_P.7, J_S11_P.9, J_S12_P.1, J_S12_P.3, J_S12_P.5, J_S12_P.7, J_S12_P.9, J_S13_P.1, J_S13_P.3, J_S13_P.5, J_S13_P.7, J_S13_P.9, J_S14_P.1, J_S14_P.3, J_S14_P.5, J_S14_P.7, J_S14_P.9
VBAT_B: J_HUB_P.2, J_HUB_P.4, J_HUB_P.6, J_HUB_P.8, J_HUB_P.10, J_S00_P.2, J_S00_P.4, J_S00_P.6, J_S00_P.8, J_S00_P.10, J_S01_P.2, J_S01_P.4, J_S01_P.6, J_S01_P.8, J_S01_P.10, J_S02_P.2, J_S02_P.4, J_S02_P.6, J_S02_P.8, J_S02_P.10, J_S03_P.2, J_S03_P.4, J_S03_P.6, J_S03_P.8, J_S03_P.10, J_S04_P.2, J_S04_P.4, J_S04_P.6, J_S04_P.8, J_S04_P.10, J_S05_P.2, J_S05_P.4, J_S05_P.6, J_S05_P.8, J_S05_P.10, J_S06_P.2, J_S06_P.4, J_S06_P.6, J_S06_P.8, J_S06_P.10, J_S07_P.2, J_S07_P.4, J_S07_P.6, J_S07_P.8, J_S07_P.10, J_S08_P.2, J_S08_P.4, J_S08_P.6, J_S08_P.8, J_S08_P.10, J_S09_P.2, J_S09_P.4, J_S09_P.6, J_S09_P.8, J_S09_P.10, J_S10_P.2, J_S10_P.4, J_S10_P.6, J_S10_P.8, J_S10_P.10, J_S11_P.2, J_S11_P.4, J_S11_P.6, J_S11_P.8, J_S11_P.10, J_S12_P.2, J_S12_P.4, J_S12_P.6, J_S12_P.8, J_S12_P.10, J_S13_P.2, J_S13_P.4, J_S13_P.6, J_S13_P.8, J_S13_P.10, J_S14_P.2, J_S14_P.4, J_S14_P.6, J_S14_P.8, J_S14_P.10

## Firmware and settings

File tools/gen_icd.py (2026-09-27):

"""Generate docs/icd.md (interface control document) from the live design data.

Usage: python tools/gen_icd.py
Every number in the tables is read from the configs or computed by the analysis tools, so the ICD cannot drift from the design.
"""
import json
import os
import sys
import tomllib

ROOT = os.path.dirname(os.path.dirname(os.path.abspath(__file__)))
sys.path.insert(0, os.path.join(ROOT, "sim"))
sys.path.insert(0, os.path.join(ROOT, "mechanical"))
import budget  # noqa: E402
import wollemi_cad as gc  # noqa: E402


def load(p):
    return tomllib.load(open(os.path.join(ROOT, p), "rb"))


def main():
    cfg = load("configs/12u_science.toml")
    geo = load("configs/12u_geometry.toml")
    st = load("configs/12u_structure.toml")
    data = load("configs/12u_data.toml")
    pin = load("electronics/card_pinout.toml")
    placement = json.load(open(os.path.join(ROOT, "mechanical", "out", "placement.json")))
    r = budget.compute(cfg)
    M, com, inertia = gc.mass_props(placement["placed"], cfg, False, geo)
    Md, comd, inertia_d = gc.mass_props(placement["placed"], cfg, True, geo)
    fr = geo["frame"]
    wg = geo["wings"]
    ox, oy, oz = fr["outer"]
    stack = wg["panels_per_wing"] * wg["panel"][2]
    span = 2 * (ox / 2 + wg["panels_per_wing"] * wg["panel"][0])
    safe = next(s for s in r["scenarios"] if s["safe"])["cons"]
    n_gkp = len(pin["gkp"]["pairs"]) * 2
    n_gkd = len(pin["gkd"]["pairs"]) * 2
    link = data["link"]

    L = []
    a = L.append
    a("# Interface control document (generated)")
    a("")
    a("Generated by `python tools/gen_icd.py` from the configs and analysis tools; do not edit by hand. Every value is a design value (analysis or estimate) unless a source is named;")
    a("the launch-provider values in section 6 are assumptions to be replaced by the provider's interface requirements document.")
    a("")
    a("## 1. Mechanical interfaces")
    a("")
    a("| Item | Value | Source |")
    a("|---|---|---|")
    a(f"| Form factor | 12U CubeSat, envelope {ox:.1f} x {oy:.1f} x {oz:.1f} mm, rails {fr['rail']} mm | `configs/12u_geometry.toml` |")
    a(f"| Mass at launch | {r['mass_kg']:.2f} kg (limit 24 kg) | `sim/budget.py` |")
    a(f"| Centre of mass (offset from the geometric centre) | ({com[0]:+.1f}, {com[1]:+.1f}, {com[2]:+.1f}) mm stowed; ({comd[0]:+.1f}, {comd[1]:+.1f}, {comd[2]:+.1f}) mm wings deployed | `mechanical/wollemi_cad.py` |")
    a(f"| Moments of inertia (kg m2) | stowed ({inertia[0]:.3f}, {inertia[1]:.3f}, {inertia[2]:.3f}); deployed ({inertia_d[0]:.3f}, {inertia_d[1]:.3f}, {inertia_d[2]:.3f}) | same |")
    a(f"| Stowed wing stack thickness | {stack:.1f} mm (allowed protrusion {fr['protrusion_limit']} mm), six hold-down posts per wing | `docs/structure.md` |")
    a(f"| External protrusions | patch antennas 4 mm; thruster nozzle flush; boom and UHF antenna stowed inside the envelope | CAD |")
    a(f"| Deployables | 2 wings x {wg['panels_per_wing']} panels ({wg['panel'][0]:.0f} x {wg['panel'][1]:.0f} x {wg['panel'][2]} mm, cells both faces), deployed span {span:.0f} mm; magnetometer boom and UHF antenna (lengths to be fixed) | CAD |")
    a(f"| Internal architecture | 2 x 2 x 3 cell grid, central spine 40 mm, notched card 100 x 100 mm (20 mm notch, 8 mm relief), 4 mm backplane gap | `docs/layout.md`, `docs/electrical-interface.md` |")
    a(f"| Number of modules | {len(placement['placed'])} placed with 0 interferences | CAD check |")
    a("")
    a("## 2. Electrical interfaces")
    a("")
    a("| Item | Value |")
    a("|---|---|")
    a("| Main bus | VBAT_A and VBAT_B, 2S LiFePO4 5.0 - 7.3 V (nominal 6.4 V); cards accept 4.5 - 8.6 V; every card has its own eFuse (trip 1.5x nominal) |")
    a(f"| Card connectors | WL-P {n_gkp} pins (power, CAN-FD A/B, PPS, SYNC, SLOT_ID, SLOT_SEL, KILL_N, FAULT_N, RESET_N, I2C, UART, SWD) and WL-D {n_gkd} pins (Ethernet, fast lanes), pitch {pin['card']['connector_pitch']} mm |")
    a("| Backplane | 15 slots plus hub per column, bussed signals daisy-chained, GND and battery planes (`electronics/gen_backplane.py`, DRC clean) |")
    a("| Battery packs | A and B: 2S2P 26650 LiFePO4, 42 Wh each; C: 5 Wh survival pack with independent charger |")
    a(f"| Solar | wings: 6 panels x 20 cells (10s2p), Vmp ~24 V, ~24 W each; body cells 0.267 m2 usable; survival string 4s2p |")
    a(f"| Power by scenario | full loads {r['consumed_w']:.1f} W average, safe mode {safe:.1f} W, burn mode 53 W (`docs/mission-simulation.md`) |")
    a("| Separation and inhibits | three independent inhibits (timer, supervisor, separation switch); remove-before-flight pin; no RF emission and no deployment until at least 30 minutes after separation (typical rideshare rule, to confirm) |")
    a("| Ground access | umbilical/charge and data port on a rail-accessible connector (design item, not yet detailed) |")
    a("")
    a("## 3. Data and command interfaces")
    a("")
    a("| Item | Value |")
    a("|---|---|")
    a("| Packet format | CCSDS Space Packet with Wollemi secondary header, CRC-16, signed telecommands (Ed25519), 27 messages (`docs/protocol-messages.md`) |")
    a("| Onboard buses | CAN-FD A and B control plane; Gigabit Ethernet data plane between the Linux computers, MMU and the S-band modem |")
    a(f"| UHF | 433 MHz amateur band, LoRa/AX.25 beacon and commands, about {link['uhf_rate_bps'] / 1000:.0f} kbps |")
    a(f"| S-band | 2.4 GHz amateur band, {link['sband_rate_bps'] / 1e6:.1f} Mbps design rate (250 kbps - 2 Mbps adaptive), efficiency {link['link_efficiency']} |")
    a(f"| Reference ground station | Pamukkale (37.9 N, 29.1 E): {link['passes_per_station_day']} passes/day of {link['pass_s']} s |")
    a("| Data products | CFDP file transfer, `.wpk` archive files and JSON index (`docs/protocol.md`) |")
    a("")
    a("## 4. Thermal interfaces")
    a("")
    a("| Item | Value |")
    a("|---|---|")
    a("| Effective face emissivity | about 0.5 (cells plus MLI patches); telescope column faces alpha 0.2 / eps 0.3 (`configs/12u_thermal.toml`) |")
    a("| Predicted ranges | electronics -10 to +33 C, battery 4 to 15 C, telescope column 13 to 25 C in nominal and eclipse orbits (`docs/thermal.md`) |")
    a("| Heaters | battery 6 W thermostat (4/9 C), telescope column 8 W (14/17 C), survival heaters 2 W |")
    a("| Conduction path | column bulkheads and spine; propulsion bay isolated; dispenser contact through the rails only |")
    a("")
    a("## 5. Structural and environmental design levels")
    a("")
    la = st["launch"]
    a("| Item | Value |")
    a("|---|---|")
    a(f"| Quasi-static design load | {la['quasi_static_g']:.0f} g all axes (local amplification {la['local_amplification']:.0f}x) |")
    a(f"| Random vibration | flat {la['random_asd_g2_per_hz']} g2/Hz, 20-2000 Hz (8.9 Grms) |")
    a(f"| Minimum first mode | {la['minimum_first_mode_hz']:.0f} Hz (estimated frame ~900 Hz, wall panels ~170 Hz, stowed wing ~190 Hz with mid posts) |")
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

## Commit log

2026-09-26 Initial commit: 12U science-first small-satellite platform design
    Requirements, architecture, power/propulsion/longevity/layout/data docs,
    TOML configs (2U/3U/6U/12U) and analysis tooling (budget, layout check,
    balance, data budget, longevity). Private until the design is complete.
2026-09-26 Add parametric CAD model: voxel packing, build123d 12U assembly, checks and renders
    - configs/12u_geometry.toml: frame, wings and module bounding boxes
    - mechanical/pack.py: numpy voxel packing with cylinders, notched card format, nadir/zenith constraints
    - mechanical/ginkgo_cad.py: full assembly, exact interference check, mass properties,
    STEP/STL exports, z-buffer renders, geometry BOM
    - Layout reconciled with real geometry; telescope aperture corrected to 85 mm (round tube fits, square does not)
    [bom_geometry.csv, ginkgo_12u_deployed.step, ginkgo_12u_deployed.stl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]
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2026-09-26 Add electrical interface spec and EPS design; update battery pack to real 26650 LiFePO4 cells
    2S2P pack is 42 Wh and ~440 g (config underestimated mass); longevity improves
    (~15 yr to 20 % fade, eclipse covered to ~36 yr).
2026-09-26 Add KiCad card template (DRC clean), pinout single source and generator
    [ginkgo_card_template.kicad_pcb]
2026-09-26 Add OreSat interoperability decision, ground-station software and real pass statistics
    Pass prediction shows ~4 passes/day mid-latitude (data plan updated from 5).
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2026-09-26 Add ADCS sizing and fix thruster line: propulsion bay on the centre line with CoM cant
    Found by the ADCS analysis and the CAD model: a column-mounted nozzle sat ~70 mm from the CoM
    (~70 uN m at 1.1 mN). Propulsion is now a bay on the -X face centre line, canted through the CoM.
    Also documents that wings must be double-sided for the power scenarios.
    [bom_geometry.csv, ginkgo_12u_deployed.step, ginkgo_12u_deployed.stl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]
2026-09-26 Add orbital thermal model, thermal design and heaters
    Finding: the spacecraft runs cold; effective face emissivity ~0.5 needed, telescope column
    isolated with low-alpha coating and 8 W heater, survival heaters 2 W. Budgets updated.
    [bom_geometry.csv, ginkgo_12u_deployed.step, ginkgo_12u_deployed.stl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]
2026-09-26 Add live verification matrix, risk register; fix double-counted heater in thermal model
    28 requirements, 19 automatic checks pass; 4 designed, 5 open. Optics heater is now simulated
    explicitly instead of also counting as constant dissipation.
2026-09-26 Add backplane strip (KiCad, DRC clean), card format changes, EPS card specification
    Pinout: distributed eFuse per card, SLOT_SEL/KILL_N hardware kill, 1.27 mm connector pitch.
    Card: 4 mm backplane gap and 8 x 8 mm outer-corner relief enforced in packing and CAD.
    [bom_geometry.csv, ginkgo_12u_deployed.step, ginkgo_12u_deployed.stl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]
2026-09-26 Add optional outreach LED flasher (10 W collimated RGB) with visibility analysis
    Also adds mechanical/reconcile.py and reshapes the radiation vault to fit beside the propulsion bay.
    [bom_geometry.csv, ginkgo_12u_deployed.step, ginkgo_12u_deployed.stl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]
2026-09-26 Add master plan, one-command regression (tools/check_all.py), violet LED beacon analysis
    Violet 405 nm is invisible to the eye but a strong camera beacon (ground long exposures, other spacecraft).
    [ginkgo_12u_deployed.step, ginkgo_12u_stowed.step]
2026-09-26 Add structural and launch-load analysis; wing stack gets six hold-down posts
    Stowed wing panel would resonate at ~99 Hz; mid-length posts raise it to ~190 Hz. 14/14 checks pass.
2026-09-26 Add orbit lifetime and debris compliance analysis; correct station-keeping delta-v (44 m/s / 50 yr at 700 km)
    Sail alone: 14-19 yr from 700 km on this model; wings only 37-42 yr; propulsive descent options costed.
2026-09-26 Add closed-loop mission simulation driving the real firmware mode manager
    60 days, two orbits, four injected faults: no brownout, correct recovery. Finding: no SCIENCE mode after Jetson loss.
2026-09-26 Add SCIENCE_LITE mode (imaging on the CM5 after Jetson loss), found by the mission simulation
    Science time in the 60-day simulation rises from 9-15 h to 76-119 h; 68 unit checks pass.
2026-09-26 Add FMEA (42 failure modes, machine-checked) and generated interface control document
    [gen_icd.py]
2026-09-26 Add 1.7 kg tungsten trim ballast: CoM y from -18.7 to -7.3 mm; docs updated
    Also flags that FOM-3 (payload mass fraction) is now 26 percent against a 35 percent target.
    [bom_geometry.csv, ginkgo_12u_deployed.step, ginkgo_12u_deployed.stl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]
2026-09-26 Fix stale safe-mode load in longevity model (3.1 W) and update longevity numbers across documents
    Battery life is ~10 yr to 20 percent fade and eclipse coverage ~28 yr after heaters and extras were added.
2026-09-26 Balance tool now takes the centre of mass from the real CAD placement (one CoM number everywhere)
    [ginkgo_12u_deployed.step, ginkgo_12u_stowed.step]
2026-09-26 Firmware and protocol review fixes: auth counter window and header checks, OTA overflow and timer wrap, FDIR event loss, survival recovery, science hysteresis, optics gate; orbit-life analysis refact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
2026-09-26 Physics review: safe-mode heater budget consistency, planning DoD unified, view factor, environment extremes
2026-09-26 Consistency fixes: live orbit/delta-v numbers, dawn-dusk pass statistics, 12 missing requirements traced and tested, LONG-3 honest, generated orbit doc
    [ginkgo_12u_deployed.step, ginkgo_12u_stowed.step]
2026-09-26 Chain check for LONG-2, doc consistency fixes, sponsor brief, plan steps 14-15
    [bom_geometry.csv, ginkgo_12u_deployed.step, ginkgo_12u_stowed.step]
2026-09-27 Physics review remaining items: Steinberg BGA constant (raised card target to 220 Hz), LED naked-eye visibility corrected to scotopic threshold (blue easily visible at 10 W, red not; beam-steering re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
    [ginkgo_12u_deployed.step, ginkgo_12u_stowed.step]
2026-09-27 Thermal model: wing panel equilibrium temperature check, off-MPP heat advisory quantified (up to ~51 W in dawn-dusk NOMINAL)
    [ginkgo_12u_deployed.step, ginkgo_12u_stowed.step]
2026-09-27 Ground kit BOM and second-anchor proposal (COLAV-4), licensing timeline, real trademark conflict found for 'Ginkgo', recommendations for operator decisions written into the SDD
    [ginkgo_12u_deployed.step, ginkgo_12u_stowed.step]
2026-09-27 Rename project from Ginkgo to Wollemi (trademark conflict found for the old name): renamed all identifiers, files, connectors (GK-*->WL-*, .gpk->.wpk), regenerated firmware, protocol, KiCad boards an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
    [ginkgo_backplane_strip.kicad_pcb, ginkgo_card_template.kicad_pcb, wollemi_12u_deployed.step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]
2026-09-27 Ground station kit: real rotator selection (SPID BIG-RAS, quantified wind-load check vs SatNOGS/SATRAN which cannot hold a 1.2m dish), updated cost range, Turkey-specific frequency coordination entry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
    [wollemi_12u_deployed.step, wollemi_12u_stowed.step]
2026-09-27 Close remaining review/traceability gaps: wing-panel frequency now uses a defensible geometric-mean estimate (fixed mass-model inconsistency, was optimistic), public relay policy written (OPEN-3/OPEN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
    [wollemi_12u_deployed.step, wollemi_12u_stowed.step]
2026-09-27 ELEC-3: EPS-A/EPS-B and survival card function-block floor plans on the real card outline (electronics/gen_eps_card.py), DRC clean; closes the placement question, schematic capture still open
    [wollemi_12u_deployed.step, wollemi_12u_stowed.step, wollemi_eps_card.kicad_pcb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]
2026-09-27 EPS card candidate part selection (v0): LT8490 MPPT/charger, BQ29209-Q1 2S balancer, LTC4359 ideal diode, TPS2597x eFuse, STM32G0B1 telemetry MCU, discrete AND-gated burn-wire driver; pinned pack C t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
    [bom_geometry.csv, wollemi_12u_deployed.step, wollemi_12u_stowed.step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]
2026-09-27 OPEN-7: SatNOGS DB integration plan; first Kaitai Struct decoder (beacon message), byte-level model verified against the real encoder (groundstation/kaitai/), wired into the regression
    [wollemi_12u_deployed.step, wollemi_12u_stowed.step]
2026-09-27 PWR-5: note bifacial-cell space heritage (distinct concept, not a resolution) and named custom-panel vendors to approach for a quote
    [wollemi_12u_deployed.step, wollemi_12u_stowed.step]
2026-09-27 Kaitai decoders for all 27 protocol messages, generated from protocol/messages.toml (protocol/gen_kaitai.py), single source with the C/Python implementations; verify_all_ksy.py checks every message's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
    [wollemi_12u_deployed.step, wollemi_12u_stowed.step]
2026-09-27 Confirmed against the real kaitai-struct-compiler: installed a JDK, downloaded kaitai-struct-compiler 0.11, compiled wollemi_protocol.ksy and round-tripped all 27 messages through the generated parse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
    [wollemi_12u_deployed.step, wollemi_12u_stowed.step]
2026-09-27 Visualization gallery and a draft English project website (not published): mechanical/render_gallery.py generates 9 static views, an exploded assembly view, a three-view engineering drawing, and 2 GI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
    [wollemi_12u_deployed.step, wollemi_12u_stowed.step]
2026-09-27 Add 'in orbit' space illustrations: mechanical/render_space.py composites the real CAD model over a procedural starfield/Earth/sun backdrop (3 scenes: deployed near Earth, deployed deep-space wide sh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
    [wollemi_12u_deployed.step, wollemi_12u_stowed.step]
2026-09-27 Make the space illustrations look like a real satellite: solar-cell grid texture on wing pixels and gold MLI foil texture on wall pixels (mechanical/render_space.py), identified per-pixel via a part-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
    [wollemi_12u_deployed.step, wollemi_12u_stowed.step]
2026-09-27 Photorealistic 'in orbit' renders via a real path tracer (Blender/Cycles): installed Blender, wrote mechanical/export_obj.py (OBJ+MTL export from the real CAD model, materials by part category) and m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
    Also applied the licensing prep discussed earlier: LICENSES/ with the real, authoritative texts (fetched from apache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
    [wollemi_12u_deployed.step, wollemi_12u_deployed_textured.obj, wollemi_12u_stowed.step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]
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2026-09-27 Add interactive 3D viewer, motion/story redesign, Japanese and Korean
    Replace the static hero image with a real-time three.js viewer of the
    actual CAD model (drag to orbit, Deployed/Stowed toggle), add animated
    stat-count-up chips, scroll-reveal motion, and two short manifesto-style
    statements between sections. Add Japanese and Korean to the translation
    pipeline (8 languages total). Fix two accumulating bugs found along the
    way: add_seo.py's duplicate-tag cleanup silently never matched (rel is a
    list in bs4, and twitter:* meta tags use name= not property=), so three
    reruns had stacked triplicate canonical/OG/Twitter/JSON-LD tags into
    every page's <head>; and the OBJ export has no vertex norm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
    [wollemi_deployed.obj, wollemi_stowed.obj]
2026-09-27 Fix the 3D viewer rendering pitch black at its default angle
    The custom OBJ exporter doesn't guarantee consistent CCW face winding,
    so computeVertexNormals() produced inward-facing normals on some faces;
    those read as unlit black under THREE.FrontSide's default single-sided
    shading, which was most of what was visible at the viewer's initial
    camera angle before auto-rotate turned enough to reach a face that
    happened to wind the other way. Set THREE.DoubleSide on every material
    instead of trying to fix winding order at export time.
    Also add short Cache-Control (5 min) to .js/.obj/.mtl/.svg responses:
    without one, Cloudflare's edge still caches these extensions by its own
    default heuristic, wh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
